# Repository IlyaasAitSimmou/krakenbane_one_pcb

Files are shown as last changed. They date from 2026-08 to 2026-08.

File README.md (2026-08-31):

# Krakenbane One — Rocketry DAQ Flight Computer

A data acquisition (DAQ) flight computer for a model rocket, designed for the Launch Canada competition. The system is two KiCad projects: a main flight computer board and a GNSS breakout that mounts separately and connects over a cable.

This is my first PCB design using SMT components, developed with support from university rocketry team members.

## Boards

| | [DAQ-V4.1](DAQ-V4.1/) | [DAQ-GPS_Breakout-V1.0](DAQ-GPS_Breakout-V1.0/) |
| --- | --- | --- |
| Role | Main flight computer  | GNSS receiver, mounted remotely |
| Outline | 38 × 100 mm | 42 × 70 mm |
| Stackup | 4-layer FR4, ~1.6 mm  | 4-layer FR4, ~1.6 mm |

The two boards are joined by a 6-pin JST GH (1.25 mm) cable carrying 3.3 V, GND, UART TX/RX, `TIMEPULSE`, and `NRESET`.

## Main board (DAQ-V4.1)

**MCU** — STM32F407VGT6 (Cortex-M4F, LQFP-100), 16 MHz crystal (NX3225GA), SWD debug on a 2×5 1.27 mm header with SWO.

**Sensors** — each on its own I²C bus, so there are no address collisions and each part can run at its full rate:

| Part | Function | Range |
| --- | --- | --- |
| LSM6DSV32X | 6-axis IMU (accel + gyro), `INT` to MCU | ±32 g |
| ADXL375 | High-g accelerometer | ±200 g |
| MS5607-02BA03 | Barometric pressure / altitude | 10–1200 mbar |

**Storage**

- microSD card (Hirose DM3BT push-pull socket) on **SPI1**, with 33 Ω series resistors on the clock and data lines, 4.7 kΩ bus pull-ups, and card-detect wired to `PE2`.
- W25Q64JV 64 Mbit NOR flash on **SPI2** for onboard logging independent of the card.

**Radio / telemetry** — XBee module on a 6-pin JST GH connector, driven from **USART2** with RTS/CTS hardware flow control.

**Power** — XT30 input at ~7.5 V → SS34 reverse-polarity diode → AP63203 synchronous buck to 3.3 V (SPM5030T 3.3 µH inductor). A separate `+3.3VA` analog rail is filtered from the digital rail through a ferrite bead for the MCU's analog supply. Power and status LEDs on board.

**Audio** — CMT-0502 magnetic buzzer switched by an AO3400A MOSFET with a B5819W flyback diode, for arming and continuity tones.

## GNSS breakout (DAQ-GPS_Breakout-V1.0)

u-blox SAM-M10Q with integrated patch antenna, broken out to a horizontal JST GH connector. Placed on its own board so the antenna can sit away from the flight computer's switching regulator and radio, with a clean ground plane underneath.

## Repository layout

```
DAQ-V4.1/                    Main flight computer
  DAQ-V4.1.kicad_sch/_pcb    Schematic and layout
  DAQ-V4.1.pdf               Schematic export
  DAQ-V4-*.pdf               Per-layer plots (copper, mask, paste, silkscreen, edge cuts)
  production/                Gerbers, BOM, pick-and-place, IPC netlist
  DRC.rpt / ERC.rpt          Latest design and electrical rule check reports
  *-backups/                 KiCad autosave history

DAQ-GPS_Breakout-V1.0/       GNSS breakout, same structure
```

Production files are generated with the KiCad Fabrication Toolkit and are formatted for JLCPCB assembly (`bom.csv` carries LCSC part numbers, `positions.csv` the placement data).

## Opening the project

Requires KiCad 8 or newer. Open `DAQ-V4.1/DAQ-V4.1.kicad_pro` or `DAQ-GPS_Breakout-V1.0/DAQ-GPS_Breakout-V1.0.kicad_pro`. Several footprints and 3D models come from project-local libraries, so open the project file rather than the `.kicad_pcb` directly.

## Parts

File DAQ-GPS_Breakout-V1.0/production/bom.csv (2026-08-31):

Designator | Footprint | Quantity | Value | LCSC Part #
C(SAM-M10Q)1, C(SAM-M10Q)3 | 0603 | 2 | C (1 µF)
C(SAM-M10Q)2, C(SAM-M10Q)4 | 0603 | 2 | C (100 nF)
C(SAM-M10Q)5 | 0603 | 1 | C (10 µF)
J6 | JST_GH_SM06B-GHS-TB_1x06-1MP_P1.25mm_Horizontal | 1 | GNSS Connector - GNSS
U3 | XCVR_SAM-M10Q-00B | 1 | SAM-M10Q-00B

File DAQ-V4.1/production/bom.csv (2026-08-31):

Designator | Footprint | Quantity | Value | LCSC Part #
C1 | 0805 | 1 | 10 µF (0805) | C162422
C10, C12, C14, C19, C20, C21, C26, C29, C9 | 0603 | 9 | 100 nF (0603) | C1591
C11, C13, C15, C18, C3, C35 | 0603 | 6 | C (100 nF) | C1591
C16, C27, C31, C32 | 0603 | 4 | C (10 µF) | C19702
C17, C24 | 0603 | 2 | 10 µF (0603) | C19702
C22 | 0603 | 1 | 1 µF (0603) | C15849
C23, C25 | 0603 | 2 | 0.1 µF (0603) | C1591
C28 | 0603 | 1 | C (47 pF) | C60302
C30 | 0603 | 1 | C (1 µF) | C15849
C4 | 0603 | 1 | 100 nF | C127833
C5, C7 | 0603 | 2 | 2.2 µF | C913904
C57, C58 | 0603 | 2 | 10 pF (0603) | C1634
COUT1, COUT2 | 0805 | 2 | 22 µF (0805) | C86816
D1 | 0603 | 1 | LED | C2287
D2 | D_SMA | 1 | SS34 | C8678
D3 | D_SOD-123 | 1 | B5819W SL | C8598
FB1 | 0603 | 1 | FCM1608KF-601T03 | C141723
IC1 | SOIC127P790X216-8N | 1 | W25Q64JVSSIQ | C179171
J1 | JST_GH_BM06B-GHS-TBT_1x06-1MP_P1.25mm_Vertical | 1 | GNSS Connector - PCB
J2 | PinHeader_2x05_P1.27mm_Vertical_SMD | 1 | Conn_02x05_Odd_Even | C5160761
J3 | JST_GH_BM06B-GHS-TBT_1x06-1MP_P1.25mm_Vertical | 1 | XBEE Connector
J4 | HRS_DM3BT-DSF-PEJS | 1 | DM3BT-DSF-PEJS | C597972
J5 | AMASS_XT30UPB-M_1x02_P5.0mm_Vertical | 1 | Conn_01x02 | C428721
L1 | IND_SPM5030T-3R3M-HZ | 1 | SPM5030T-3R3M-HZ | C518955
LS2 | XDCR_CMT-0502-75-SMT-TR | 1 | CMT-0502-75-SMT-TR
POWER_ON_LED1 | 0603 | 1 | RED | C2286
Q1 | SOT95P280X125-3N | 1 | AO3400A | C20917
R(PULL)1, R(PULL)15, R(PULL)16, R(PULL)18, R(PULL)19, R(PULL)2 | 0603 | 6 | R (4.7 kΩ) | C23046
R(PULL)3, R(PULL)4, R(T)2 | 0603 | 3 | R (10 kΩ) | C22790
R(PULL)9, R7 | 0603 | 2 | R (300 Ω) | C23025
R(T)1 | 0603 | 1 | R (100 Ω) | C22775
R_PULL_FLASH_1 | 0603 | 1 | 10 kΩ | C22790
R_PULL_MICROSD_1, R_PULL_MICROSD_2, R_PULL_MICROSD_3, R_PULL_MICROSD_4, R_PULL_MICROSD_5, R_PULL_MICROSD_6 | 0603 | 6 | 4.7 kΩ | C23046
R_SERIES_MICROSD_1, R_SERIES_MICROSD_2, R_SERIES_MICROSD_3 | 0603 | 3 | 33 Ω | C23140
U2 | LGA-14L_2p5X3p0X0p86_STM | 1 | LSM6DSV32XTR | C22461202
U4 | LGA_CC-14-1_ADI | 1 | ADXL375BCCZ | C579466
U5 | SON125P300X500X100-8N | 1 | MS560702BA03-50 | C97627
U7 | LQFP-100_14x14mm_P0.5mm | 1 | STM32F407VGTx | C12345
U9 | TSOT-23-6 | 1 | AP63203WU | C780769
XTAL1 | NX3225GA-16.000M-STD-CRG-2_NDK | 1 | NX3225GA-16.000M-STD-CRG-2 | C156247

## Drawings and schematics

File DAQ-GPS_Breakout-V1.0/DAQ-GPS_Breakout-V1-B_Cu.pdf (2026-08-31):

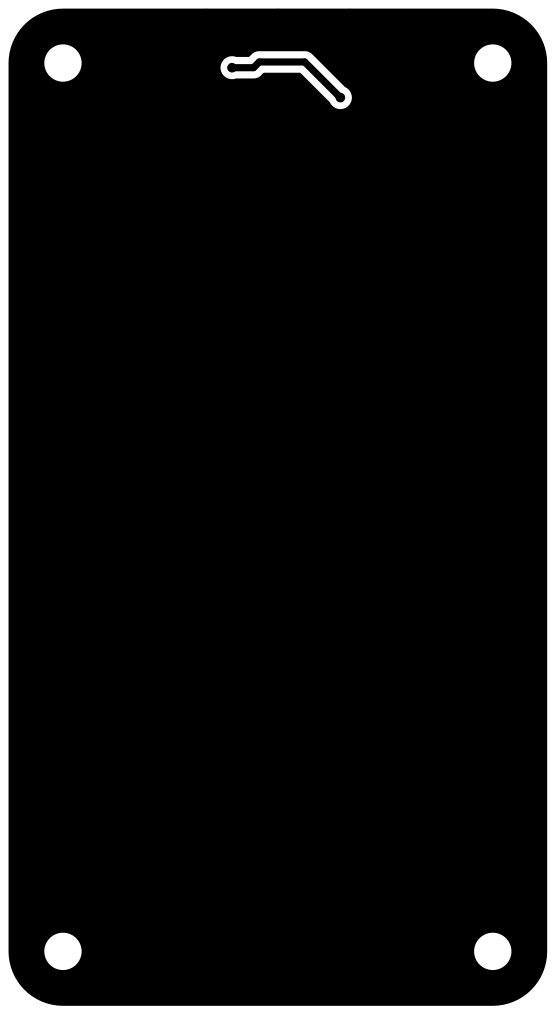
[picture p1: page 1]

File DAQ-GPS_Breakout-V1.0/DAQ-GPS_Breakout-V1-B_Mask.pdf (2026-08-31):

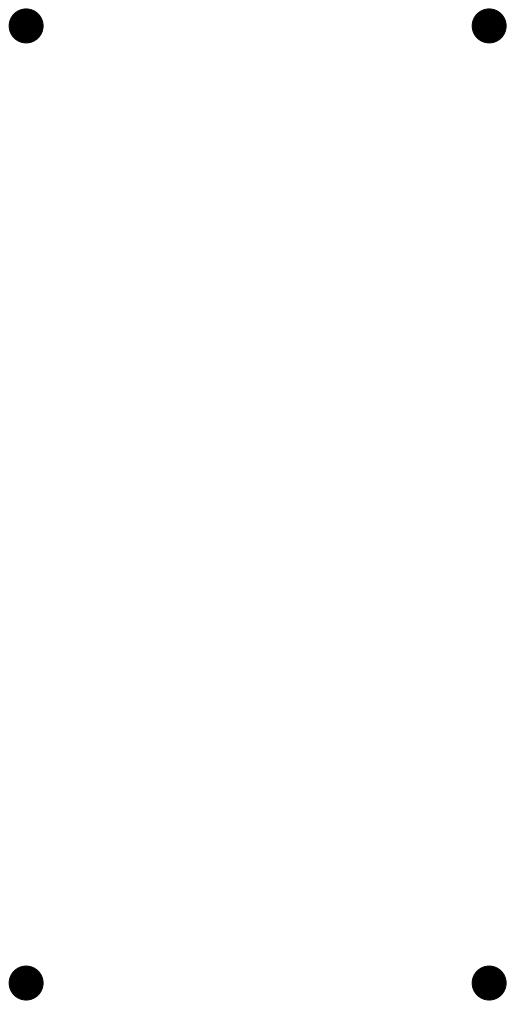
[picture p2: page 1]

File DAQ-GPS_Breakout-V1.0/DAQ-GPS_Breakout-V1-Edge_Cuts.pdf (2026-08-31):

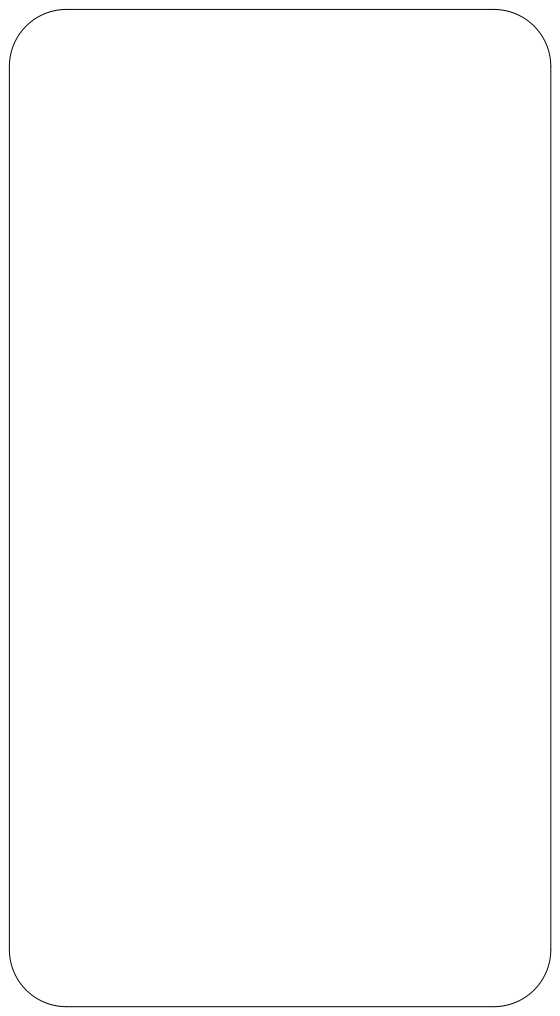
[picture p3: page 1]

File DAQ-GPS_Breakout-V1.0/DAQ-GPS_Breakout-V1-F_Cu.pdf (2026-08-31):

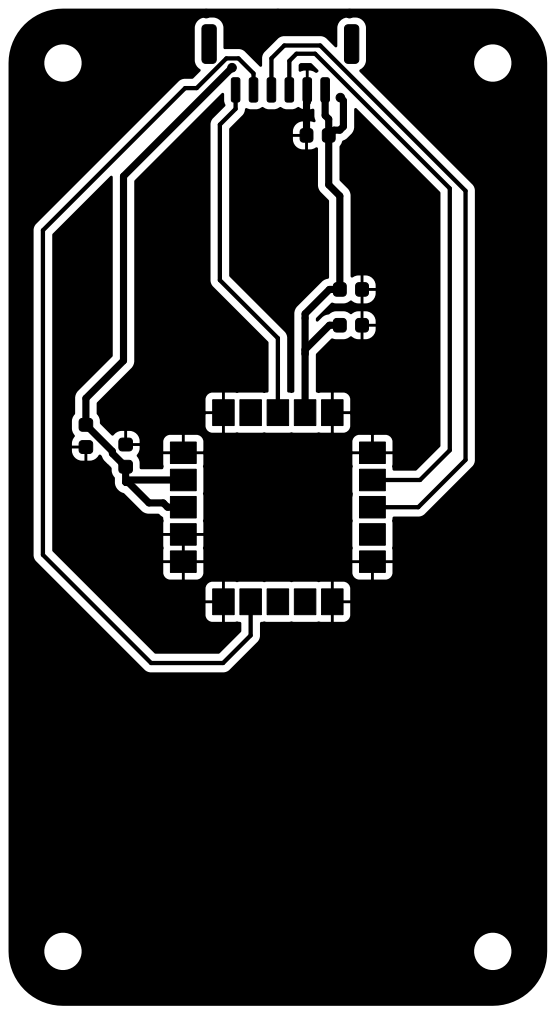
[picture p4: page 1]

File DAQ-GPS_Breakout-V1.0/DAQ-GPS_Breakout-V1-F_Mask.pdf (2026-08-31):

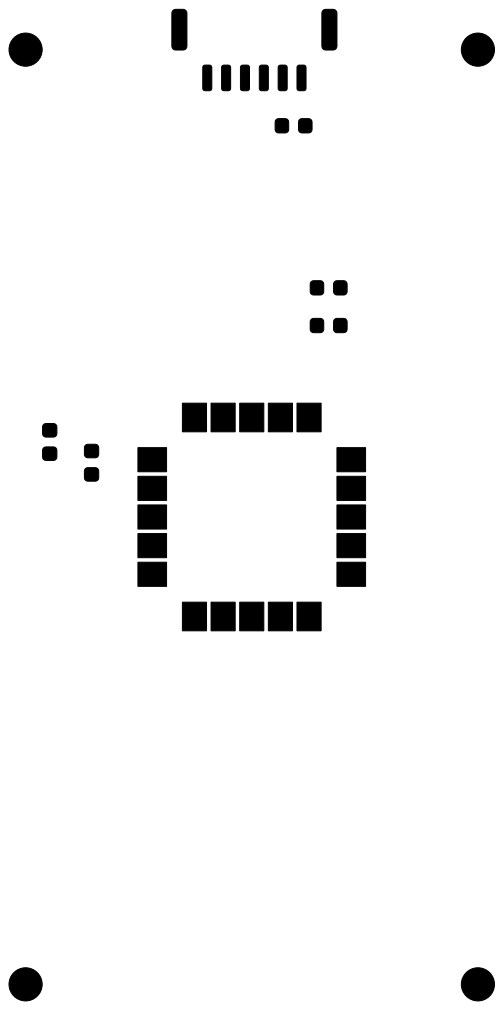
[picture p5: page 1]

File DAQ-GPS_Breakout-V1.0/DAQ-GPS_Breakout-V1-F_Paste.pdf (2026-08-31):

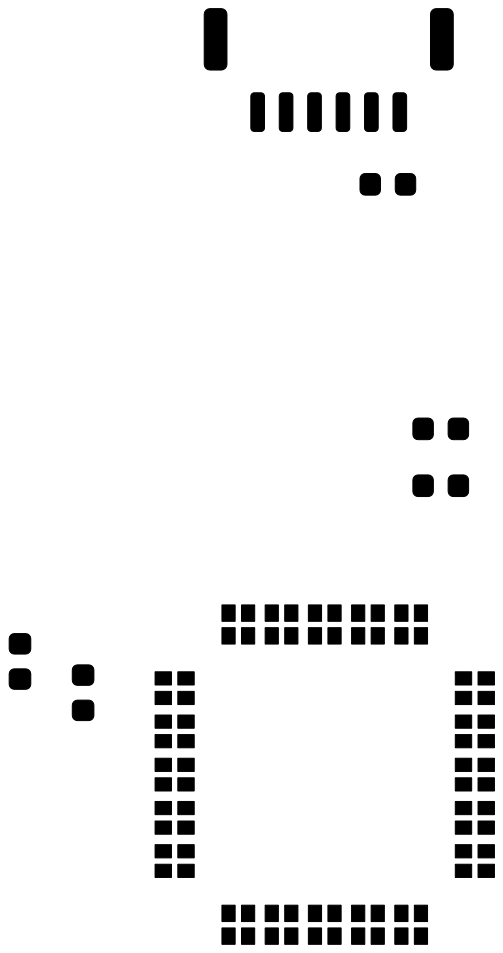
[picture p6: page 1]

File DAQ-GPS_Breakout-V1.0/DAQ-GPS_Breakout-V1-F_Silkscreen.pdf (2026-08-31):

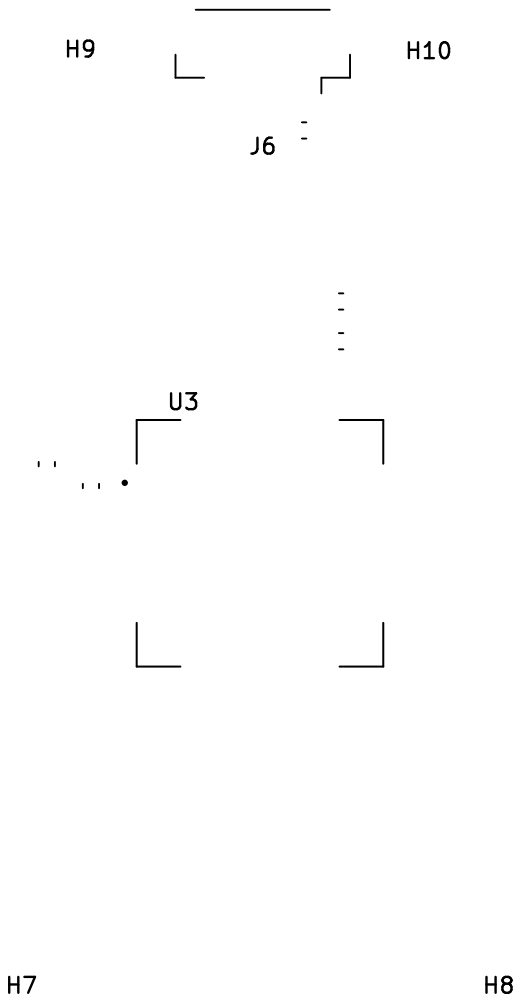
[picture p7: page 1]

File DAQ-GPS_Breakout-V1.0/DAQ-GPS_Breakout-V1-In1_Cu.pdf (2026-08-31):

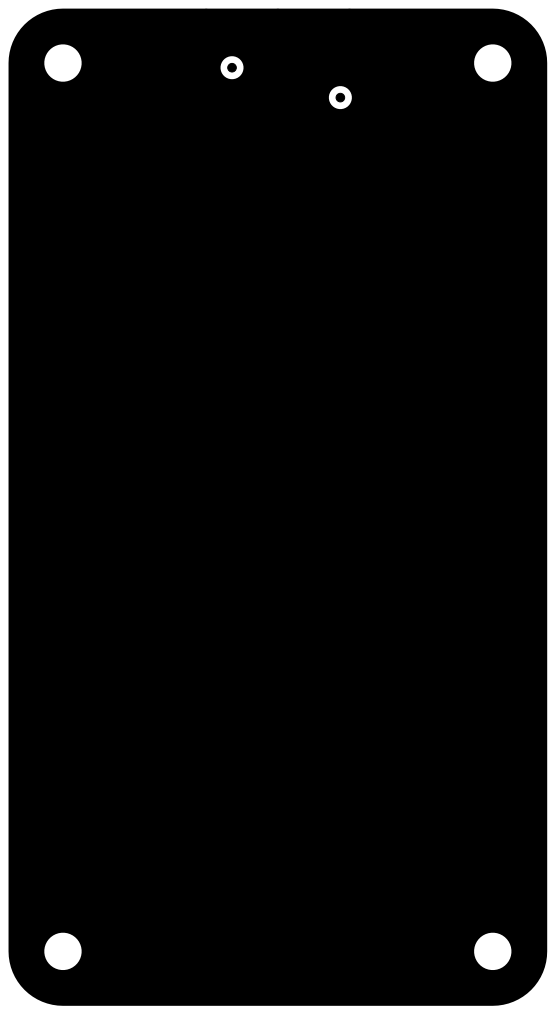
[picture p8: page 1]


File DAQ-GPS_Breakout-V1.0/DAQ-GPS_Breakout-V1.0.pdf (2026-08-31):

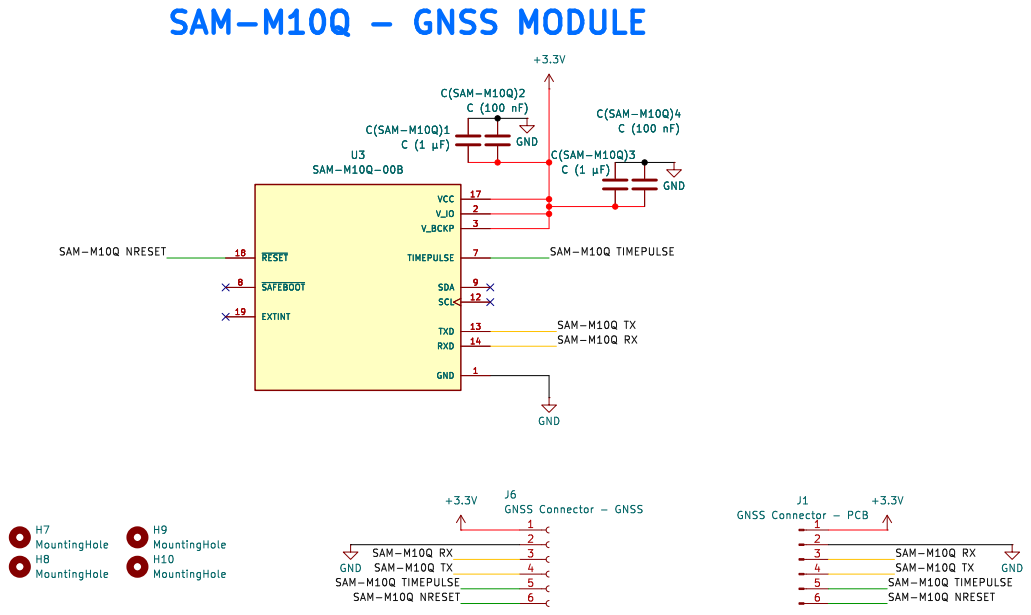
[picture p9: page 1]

SAM-M10Q NRESET SAM-M10Q RX
SAM-M10Q NRESET SAM-M10Q TX
SAM-M10Q TIMEPULSE

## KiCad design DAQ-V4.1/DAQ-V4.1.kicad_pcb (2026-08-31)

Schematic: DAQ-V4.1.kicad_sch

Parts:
C1: 10 µF (0805); C_0805_2012Metric; LCSC Part # C162422
C3, C11, C13, C15, C18, C35: C (100 nF); C_0603_1608Metric; LCSC Part # C1591
C4: 100 nF; C_0603_1608Metric; LCSC Part # C127833
C5, C7: 2.2 µF; C_0603_1608Metric; LCSC Part # C913904
C9, C10, C12, C14, C19, C20, C21, C26, C29: 100 nF (0603); C_0603_1608Metric; LCSC Part # C1591
C16, C27, C31, C32: C (10 µF); C_0603_1608Metric; LCSC Part # C19702
C17, C24: 10 µF (0603); C_0603_1608Metric; LCSC Part # C19702
C22: 1 µF (0603); C_0603_1608Metric; LCSC Part # C15849
C23, C25: 0.1 µF (0603); C_0603_1608Metric; LCSC Part # C1591
C28: C (47 pF); C_0603_1608Metric; LCSC Part # C60302
C30: C (1 µF); C_0603_1608Metric; LCSC Part # C15849
C57, C58: 10 pF (0603); C_0603_1608Metric; LCSC Part # C1634
COUT1, COUT2: 22 µF (0805); C_0805_2012Metric; LCSC Part # C86816
D1: LED; LED_0603_1608Metric; LCSC Part # C2287
D2: SS34; D_SMA; LCSC Part # C8678
D3: B5819W SL; D_SOD-123; LCSC Part # C8598
FB1: FCM1608KF-601T03; L_0603_1608Metric; LCSC Part # C141723
H1, H2, H3, H4, H5, H6: MountingHole; MountingHole_2.2mm_M2
IC1: W25Q64JVSSIQ; SOIC127P790X216-8N; Mouser Part Number 454-W25Q64JVSSIQ
J1: GNSS Connector - PCB; JST_GH_BM06B-GHS-TBT_1x06-1MP_P1.25mm_Vertical
J2: Conn_02x05_Odd_Even; PinHeader_2x05_P1.27mm_Vertical_SMD; LCSC Part # C5160761
J3: XBEE Connector; JST_GH_BM06B-GHS-TBT_1x06-1MP_P1.25mm_Vertical
J4: DM3BT-DSF-PEJS; HRS_DM3BT-DSF-PEJS; LCSC Part # C597972
J5: Conn_01x02; AMASS_XT30UPB-M_1x02_P5.0mm_Vertical; LCSC Part # C428721
L1: SPM5030T-3R3M-HZ; IND_SPM5030T-3R3M-HZ; PARTREV 20210423; LCSC Part # C518955
LS2: CMT-0502-75-SMT-TR; XDCR_CMT-0502-75-SMT-TR; PARTREV 1.0; DigiKey_Part_Number 102-CMT-0502-75-SMT-CT-ND
Power_On_LED1: RED; LED_0603_1608Metric; LCSC Part # C2286
Q1: AO3400A; SOT95P280X125-3N; PARTREV L; LCSC Part # C20917
R7: R (300 Ω); R_0603_1608Metric; LCSC Part # C23025
R(PULL)1, R(PULL)2, R(PULL)15, R(PULL)16, R(PULL)18, R(PULL)19: R (4.7 kΩ); R_0603_1608Metric; LCSC Part # C23046
R(PULL)3, R(PULL)4: R (10 kΩ); R_0603_1608Metric; LCSC Part # C22790
R(PULL)9: R (300 Ω); R_0603_1608Metric; LCSC Part # C23025
R(T)1: R (100 Ω); R_0603_1608Metric; LCSC Part # C22775
R(T)2: R (10 kΩ); R_0603_1608Metric; LCSC Part # C22790
R_Pull_Flash_1: 10 kΩ; R_0603_1608Metric; LCSC Part # C22790
R_Pull_MicroSD_1, R_Pull_MicroSD_2, R_Pull_MicroSD_3, R_Pull_MicroSD_4, R_Pull_MicroSD_5, R_Pull_MicroSD_6: 4.7 kΩ; R_0603_1608Metric; LCSC Part # C23046
R_Series_MicroSD_1, R_Series_MicroSD_2, R_Series_MicroSD_3: 33 Ω; R_0603_1608Metric; LCSC Part # C23140
U2: LSM6DSV32XTR; LGA-14L_2p5X3p0X0p86_STM; LCSC C22461202
U4: ADXL375BCCZ; LGA_CC-14-1_ADI; LCSC Part # C579466
U5: MS560702BA03-50; SON125P300X500X100-8N; LCSC Part # C97627
U7: STM32F407VGTx; LQFP-100_14x14mm_P0.5mm; LCSC Part # C12345
U9: AP63203WU; TSOT-23-6; LCSC Part # C780769
XTAL1: NX3225GA-16.000M-STD-CRG-2; NX3225GA-16.000M-STD-CRG-2_NDK; LCSC Part # C156247

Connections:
+3.3V: C3.2, C9.1, C10.1, C11.1, C12.1, C13.2, C14.1, C15.2, C16.2, C17.1, C18.2, C19.1, C20.1, C23.2, C24.2, C25.2, C26.1, C27.2, C28.2, C30.2, C31.2, C32.1, COUT1.1, COUT2.1, D3.1 (K), FB1.2, IC1.3 (~WP_(IO2)), IC1.7 (~HOLD_OR_/RESET_(IO3)), IC1.8 (VCC), J1.1, J2.1, J3.1, J4.4 (VDD), L1.2, LS2.P, Power_On_LED1.2 (A), R(PULL)1.1, R(PULL)2.1, R(PULL)3.2, R(PULL)15.1, R(PULL)16.1, R(PULL)18.1, R(PULL)19.1, R_Pull_Flash_1.1, R_Pull_MicroSD_1.2, R_Pull_MicroSD_2.2, R_Pull_MicroSD_3.2, R_Pull_MicroSD_4.2, R_Pull_MicroSD_5.2, R_Pull_MicroSD_6.1, U2.5 (VDD_IO), U2.8 (VDD), U2.10 (OCS_AUX), U2.11 (SDO_AUX), U2.12 (CS), U4.1 (VDD_I/O), U4.6 (VS), U4.7 (*CS), U4.12 (SDO/ALT_ADDRESS), U5.1 (VDD), U5.2 (PS), U7.6 (VBAT), U7.11 (VDD), U7.19 (VDD), U7.28 (VDD), U7.50 (VDD), U7.75 (VDD), U7.100 (VDD), U9.1 (FB)
+3.3VA: C21.1, C22.1, C35.1, FB1.1, U7.21 (VREF+), U7.22 (VDDA)
+7.5V: D2.2 (A), J5.2
/ADXL375 SCL: R(PULL)19.2, U4.14 (SCL/SCLK), U7.67 (PA8)
/ADXL375 SDA: R(PULL)18.2, U4.13 (SDA/SDI/SDIO), U7.66 (PC9)
/BOOT0: R(PULL)4.1, U7.94 (BOOT0)
/LSM6DSV INT: U2.4 (INT1), U7.90 (PB4)
/LSM6DSV SCL: R(PULL)1.2, U2.13 (SCL), U7.92 (PB6)
/LSM6DSV SDA: R(PULL)2.2, U2.14 (SDA), U7.93 (PB7)
/MS5607 SCL: R(PULL)15.2, U5.8 (SCLK), U7.47 (PB10)
/MS5607 SDA: R(PULL)16.2, U5.7 (SDI/SDA), U7.48 (PB11)
/NRST: C29.2, J2.10, R(PULL)3.1, U7.14 (NRST)
/PE2: J4.SW-A, R_Pull_MicroSD_6.2, U7.1 (PE2)
/PWR_LED_K: Power_On_LED1.1 (K), R(PULL)9.2
/SAM-M10Q NRESET: J1.6, U7.87 (PD6)
/SAM-M10Q RX: J1.3, U7.23 (PA0)
/SAM-M10Q TIMEPULSE: J1.5, U7.86 (PD5)
/SAM-M10Q TX: J1.4, U7.24 (PA1)
/SPI1_MISO: J4.7 (DAT0), R_Pull_MicroSD_1.1, R_Series_MicroSD_2.1
/SPI1_MOSI: J4.3 (CMD), R_Pull_MicroSD_2.1, R_Series_MicroSD_3.1
/SPI1_NSS: J4.2 (DAT3/CD), R_Pull_MicroSD_3.1, U7.29 (PA4)
/SPI1_SCK: J4.5 (CLK), R_Series_MicroSD_1.1
/SPI2_MISO: IC1.2 (DO_(IO1)), U7.53 (PB14)
/SPI2_MOSI: IC1.5 (DI_(IO0)), U7.54 (PB15)
/SPI2_NSS: IC1.1 (~CS), R_Pull_Flash_1.2, U7.51 (PB12)
/SPI2_SCK: IC1.6 (CLK), U7.52 (PB13)
/SWCLK: J2.4, U7.76 (PA14)
/SWDIO: J2.2, U7.72 (PA13)
/SWO: J2.6, U7.89 (PB3)
/USART2_CTS: J3.4, U7.84 (PD3)
/USART2_RTS: J3.5, U7.85 (PD4)
/USART2_RX: J3.3, U7.26 (PA3)
/USART2_TX: J3.2, U7.25 (PA2)
GND: C1.2, C3.1, C5.1, C7.1, C9.2, C10.2, C11.2, C12.2, C13.1, C14.2, C15.1, C16.1, C17.2, C18.1, C19.2, C20.2, C21.2, C22.2, C23.1, C24.1, C25.1, C26.2, C27.1, C28.1, C29.1, C30.1, C31.1, C32.2, C35.2, C57.1, C58.1, COUT1.2, COUT2.2, D1.1 (K), IC1.4 (GND), J1.2, J2.3, J2.5, J2.9, J3.6, J4.6 (VSS), J4.S1 (SHIELD), J4.S2 (SHIELD), J4.S3 (SHIELD), J4.S4 (SHIELD), J4.SW-B, J5.1, Q1.2, R(PULL)4.2, R(PULL)9.1, R(T)2.2, U2.1 (SDO/SA0), U2.2 (SDX/AH1/QVAR1), U2.3 (SCX/AH2/QVAR2), U2.6 (GND), U2.7 (GND), U4.2 (GND), U4.4 (GND), U4.5 (GND), U5.3 (GND), U5.4 (~CSB), U5.5 (~CSB), U7.10 (VSS), U7.20 (VSSA), U7.27 (VSS), U7.74 (VSS), U7.99 (VSS), U9.4 (GND), XTAL1.2, XTAL1.4
unnamed: D1.2 (A), R7.2
unnamed: C1.1, D2.1 (K), U9.2 (EN), U9.3 (IN)
unnamed: D3.2 (A), LS2.N, Q1.3
unnamed: J4.8 (DAT1), R_Pull_MicroSD_5.1
unnamed: J4.1 (DAT2), R_Pull_MicroSD_4.1
unnamed: Q1.1, R(T)1.1, R(T)2.1
unnamed: R_Series_MicroSD_1.2, U7.30 (PA5)
unnamed: R_Series_MicroSD_2.2, U7.31 (PA6)
unnamed: R_Series_MicroSD_3.2, U7.32 (PA7)
unnamed: R7.1, U7.39 (PE8)
unnamed: R(T)1.2, U7.40 (PE9)
unnamed: C57.2, U7.12 (PH0), XTAL1.1
unnamed: C58.2, U7.13 (PH1), XTAL1.3
unnamed: C5.2, U7.49 (VCAP_1)
unnamed: C7.2, U7.73 (VCAP_2)
unnamed: C4.1, U9.6 (BST)
unnamed: C4.2, L1.1, U9.5 (SW)

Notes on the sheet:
MOUNTING HOLES
JTAG/SWD PINS
MS5607 - BAROMETRIC PRESSURE SENSOR
LSM6DSV32 - 6-AXIS INERTIAL MEASUREMENT UNIT
STM32F407 - MICROCONTROLLER
MAIN BOARD
JST-GH GNSS CONNECTORS
SENSOR SUITE
SAM-M10Q - GNSS MODULE
ADXL375 - HIGH G ACCELEROMETER
XBEE CONNECTOR
DM3BT-DSF-PEJS - MICROSD CONNECTOR
GNSS BOARD
GNSS
DATA STORAGE
W25Q64 - FLASH CHIP
XT30 CONNECTORS
BUCK CONVERTER
AP63203 - BUCK SWITCHING REGULATOR

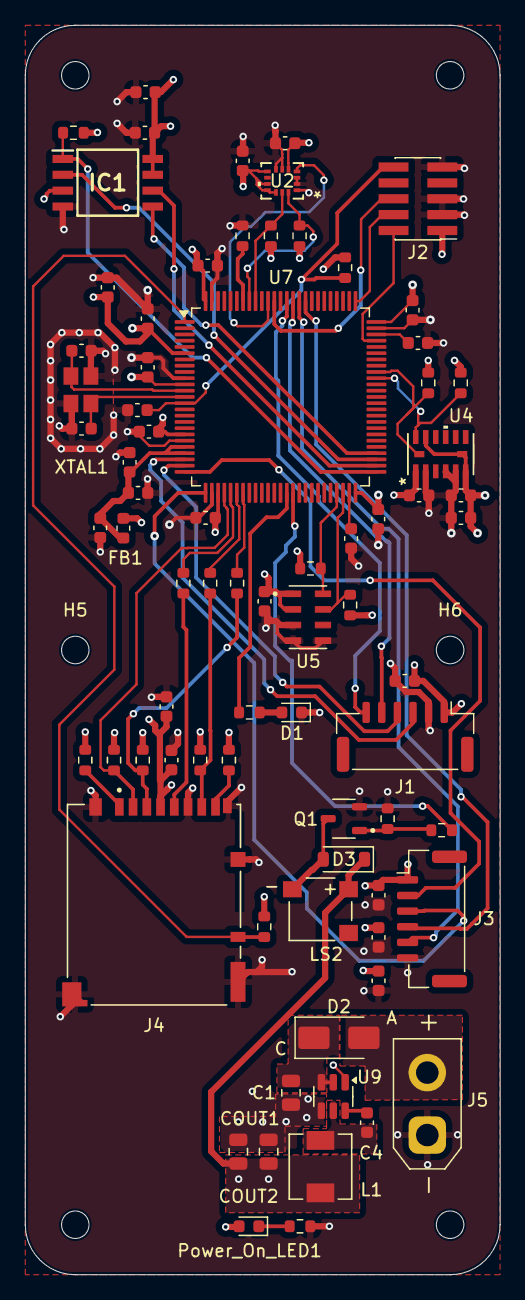
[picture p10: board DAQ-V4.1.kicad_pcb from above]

Board: 4 copper layers, 38.0 x 100.0 mm, 82 parts (0 on the bottom side), 51 nets.

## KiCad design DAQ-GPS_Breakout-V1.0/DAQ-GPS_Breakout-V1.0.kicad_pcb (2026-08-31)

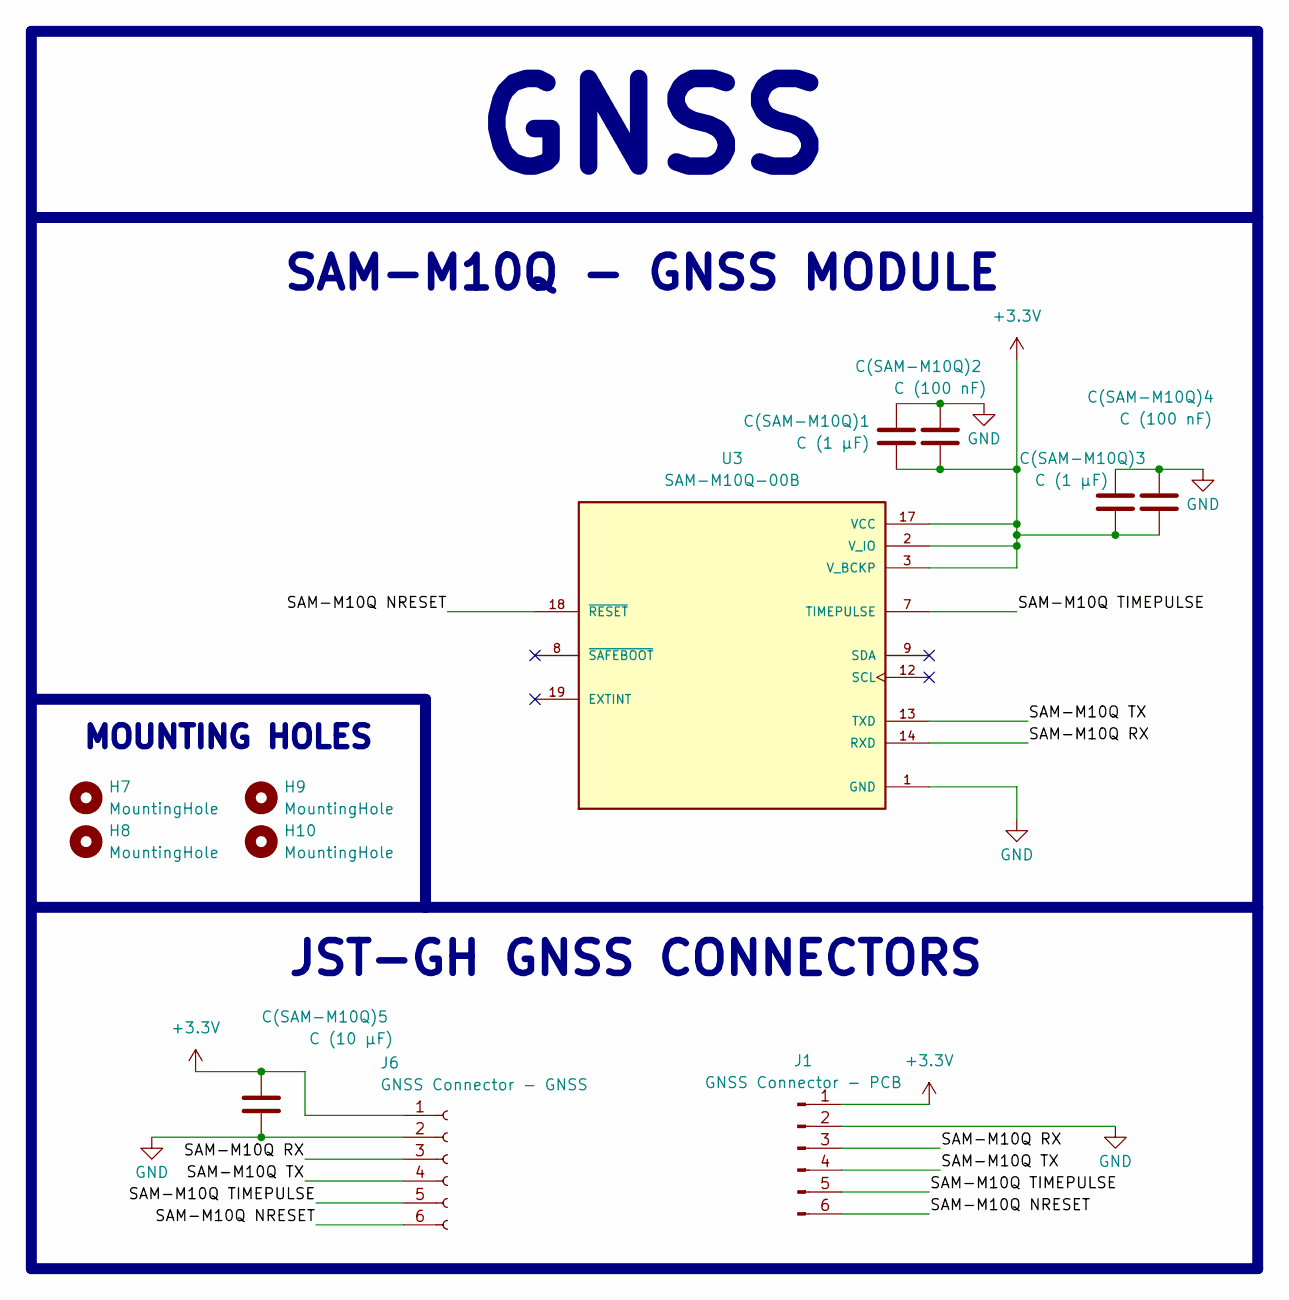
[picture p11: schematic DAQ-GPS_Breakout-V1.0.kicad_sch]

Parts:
C(SAM-M10Q)1, C(SAM-M10Q)3: C (1 µF); C_0603_1608Metric
C(SAM-M10Q)2, C(SAM-M10Q)4: C (100 nF); C_0603_1608Metric
C(SAM-M10Q)5: C (10 µF); C_0603_1608Metric
H7, H8, H9, H10: MountingHole; MountingHole_2.2mm_M2
J1: GNSS Connector - PCB; JST_GH_BM06B-GHS-TBT_1x06-1MP_P1.25mm_Vertical
J6: GNSS Connector - GNSS; JST_GH_SM06B-GHS-TB_1x06-1MP_P1.25mm_Horizontal
U3: SAM-M10Q-00B; XCVR_SAM-M10Q-00B; PARTREV R03

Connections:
+3.3V: C(SAM-M10Q)1.2, C(SAM-M10Q)2.2, C(SAM-M10Q)3.2, C(SAM-M10Q)4.2, C(SAM-M10Q)5.1, J1.1, J6.1, U3.2 (V_IO), U3.3 (V_BCKP), U3.17 (VCC)
/SAM-M10Q NRESET: J1.6, J6.6, U3.18 (~RESET)
/SAM-M10Q RX: J1.3, J6.3, U3.14 (RXD)
/SAM-M10Q TIMEPULSE: J1.5, J6.5, U3.7 (TIMEPULSE)
/SAM-M10Q TX: J1.4, J6.4, U3.13 (TXD)
GND: C(SAM-M10Q)1.1, C(SAM-M10Q)2.1, C(SAM-M10Q)3.1, C(SAM-M10Q)4.1, C(SAM-M10Q)5.2, J1.2, J6.2, U3.1 (GND), U3.4 (GND), U3.5 (GND), U3.6 (GND), U3.10 (GND), U3.11 (GND), U3.15 (GND), U3.16 (GND), U3.20 (GND)

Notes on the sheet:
MOUNTING HOLES
GNSS
JST-GH GNSS CONNECTORS
SAM-M10Q - GNSS MODULE

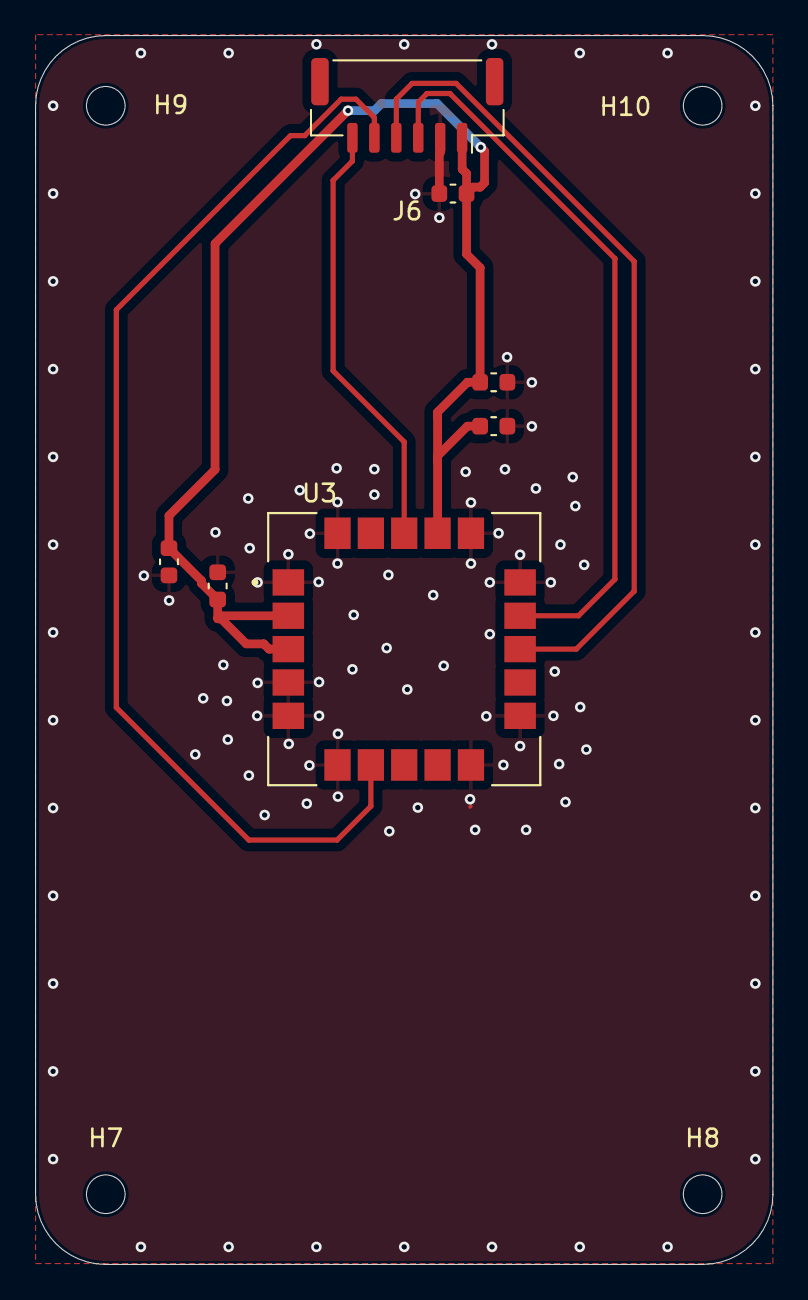
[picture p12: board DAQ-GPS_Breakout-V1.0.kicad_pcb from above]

Board: 4 copper layers, 42.0 x 70.0 mm, 11 parts (0 on the bottom side), 6 nets.
